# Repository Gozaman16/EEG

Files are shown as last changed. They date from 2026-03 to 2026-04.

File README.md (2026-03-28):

# EpiScreen EEG Electrode System

Semi-dry EEG electrode system with resin-printable silicone casting molds.
Designed for ISEF 2026.

## Components

| Component | File(s) | Description |
|---|---|---|
| EpiScreen electrode mold | `stl/episcreen_mold_bottom.stl` / `_top.stl` | 24 mm standard electrode, 2-part mold |
| NeoGuard neonatal mold | `stl/neoguard_mold_bottom.stl` / `_top.stl` | 15 mm neonatal electrode, 2-part mold |
| HairSite hair-contact mold | `stl/hairsite_mold_bottom.stl` / `_top.stl` | 24 mm electrode + 7 penetrating pins |
| ImpactGuard helmet adapter | `stl/impactguard_helmet_adapter.stl` | Snap-fit mount for sports helmets |
| Adult headband mount | `stl/headband_mount_adult.stl` | 22 mm elastic band clip, 24 mm electrode |
| Neonatal headband mount | `stl/headband_mount_neonatal.stl` | 16 mm silicone band clip, 15 mm electrode |

## Assembly Renders (300 DPI, ISEF-ready)

| Render | File | Description |
|---|---|---|
| Family photo | `renders/assembly_family.png` | All components side by side with scale bar & Turkish Lira coin reference |
| Exploded view | `renders/assembly_exploded.png` | All electrode layers separated vertically with assembly arrows |
| Cross-section | `renders/assembly_cross_section.png` | Internal features with full dimensioning and material callouts |

## Parametric Source (OpenSCAD)

All geometry is parametric via `scad/params.scad`. Edit dimensions there and
re-run `scripts/generate_stl.py` (uses `trimesh` + `manifold3d`) to regenerate STLs,
or open `.scad` files in OpenSCAD 2021+ for interactive editing.

```
scad/
  params.scad                 ← all dimensions in one place
  episcreen_mold_bottom.scad
  episcreen_mold_top.scad
  neoguard_mold_bottom.scad
  neoguard_mold_top.scad
  hairsite_mold_bottom.scad
  hairsite_mold_top.scad
  impactguard_helmet_adapter.scad
  headband_mount_adult.scad
  headband_mount_neonatal.scad
  assembly_family.scad
  assembly_exploded.scad
  assembly_cross_section.scad
```

## Regenerating outputs

```bash
# Install deps
pip install trimesh manifold3d numpy matplotlib pillow

# Generate all STL files
python3 scripts/generate_stl.py

# Render publication PNGs (300 DPI)
python3 scripts/render_family.py
python3 scripts/render_exploded.py
python3 scripts/render_cross_section.py
```

## Electrode Design Specs

### EpiScreen (24 mm)
- Outer diameter: 24 mm, total height: 10 mm
- FR-4 disk seat at 3 mm, reservoir ring ID/OD 13/19 mm × 1.5 mm
- 3× microchannel guide holes (Ø 0.6 mm, 37.5° angle)
- Spiral exposure platform: Ø 8 mm × 0.8 mm
- Cable exit: 3–4 mm wide funnel notch
- Mold: 32 mm OD, 4× Ø 2 mm alignment pins, 2× Ø 1 mm vent holes

### NeoGuard (15 mm)
- Outer diameter: 15 mm, total height: 8 mm
- FR-4 seat at 2.5 mm, reservoir ring ID/OD 8.5/12 mm × 1.2 mm
- Mold: 22 mm OD

### HairSite (24 mm + pins)
- Same body as EpiScreen, height 12 mm
- 7 penetrating pins: 1 centre + 6 on Ø 12 mm circle
- Pin diameter: 1.2 mm, length: 8 mm

## Print Settings (SLA/DLP)
- Layer height: 0.05 mm
- Resin: standard or flexible resin (depends on electrode flexibility needed)
- Supports: on mold exterior only — never inside cavity
- Minimum feature: 0.3 mm (microchannel holes, texture rings)

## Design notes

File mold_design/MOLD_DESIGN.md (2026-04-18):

# EEG Electrode Mold Design — EpiScreen / NeoGuard / HairSite

Two-part SLA-resin 3D-printable molds for casting semi-dry EEG electrodes
in Ecoflex 00-50 silicone. Three variants share a common architecture.

| Variant | Target use | Electrode OD | Pins |
|---|---|---|---|
| EpiScreen | Adult | 24 mm | — |
| NeoGuard | Neonatal | 15 mm | — |
| HairSite | Adult, through hair | 24 mm | 7 (1 centre + 6 on 6 mm radius) |

All mold SCAD sources live in `scad/`. This directory (`mold_design/`)
contains symlinks to those sources plus rendered STL / PNG assets for
non-mold parts (headband, impactguard, band guide).

## Files

| File | Description |
|---|---|
| `../scad/params.scad` | Shared parameters + utility modules |
| `../scad/episcreen_mold_bottom.scad`  | EpiScreen bottom mold |
| `../scad/episcreen_mold_top.scad` | EpiScreen top mold |
| `../scad/neoguard_mold_bottom.scad` | NeoGuard bottom mold |
| `../scad/neoguard_mold_top.scad` | NeoGuard top mold |
| `../scad/hairsite_mold_bottom.scad` | HairSite bottom mold |
| `../scad/hairsite_mold_top.scad` | HairSite top mold |

## Architecture

Each electrode is cast from **two silicone pours**, separated by a
barrier coat. The result is a **LOWER** silicone piece and an **UPPER**
silicone piece that mechanically interlock but are **separable for
service** (FR-4 swap, cleaning, inspection).

Key design decisions:

- **Funnel IS the reservoir.** A truncated-cone void inside the lower
  silicone holds the electrolyte. No separate reservoir ring.
- **Impedance ring** sits on the inner funnel wall, wetted
  automatically by electrolyte.
- **Lower silicone** owns FR-4, cables, funnel, sensing tip, impedance
  ring. **Upper silicone** is a thin lid with a refill port.
- **When opened, FR-4 stays with the lower half** and is accessible
  from above.

## Cross-Section Diagram

```
 ┌──────────────────────────┐
 │   UPPER SILICONE (lid)   │  ← refill port through this
 ├──────────────────────────┤  ← openable interlock interface
 │        FR-4 card         │  ← sits in recess on lower silicone's upper face
 ├──────────────────────────┤
 │                          │
 │      LOWER SILICONE      │
 │                          │
 │     ╲             ╱      │  ← funnel walls
 │      ╲   ▓▓▓▓▓   ╱       │  ← electrolyte (fills funnel = reservoir)
 │       ╲▓▓▓▓▓▓▓▓▓╱        │
 │        ╲▓▓▓▓▓▓▓╱         │
 │         ╲ ███ ╱          │  ← sensing tip (protrudes 0.1 mm)
 └──────────┴───┴───────────┘
           SKIN
```

## Parameter Table

| Parameter | EpiScreen | NeoGuard | HairSite  | Notes |
|---|---|---|---|---|
| Electrode OD (mm) | 24.0 | 15.0 | 24.0 | `*_OD` |
| Electrode height (mm)  | 10.0 | 8.0 | 12.0 | `*_H` |
| Mold OD (mm) | 32.0 | ~22.0 | 32.0 | = OD + 2·WALL + 4 |
| Bottom mold height | 5.0 | 4.0 | 6.0 | `*_BOT_H` |
| Top mold height | 6.5 | 5.5 | 7.5 | `*_TOP_H` |
| Pour hole Ø | 6.0 | 4.0 | 6.0 | |
| FR-4 Ø × thickness | 19×1.6 | 12×1.0 | 19×1.6 | flush with top of lower silicone |
| Funnel top Ø (FR-4) | 10.0 | 6.0 | 10.0 | `*_FUN_TOP_D` |
| Funnel bottom Ø (skin) | 18.0 | 11.0 | 18.0 | `*_FUN_BOT_D` |
| Funnel height | 3.0 | 2.5 | 3.0 | `*_FUN_H` |
| Sensing tip Ø | 3.0 | 2.0 | 3.0 | `*_SENSE_TIP_D` |
| Sensing tip protrude | 0.1 | 0.1 | 0.1 | past funnel bottom rim |
| Impedance ring width | 1.5 | 1.0 | 1.5 | on inner funnel wall |
| Impedance ring thick | 0.3 | 0.25 | 0.3 | generous — no "powdered sugar" tolerances |
| Cable strategy | C (2ch) | B (2×Ø)  | C (2ch) | see below |
| Cable channel W × H | 1.5 × 1.8 | Ø 1.5 | 1.5 × 1.8 | 1 mm cable + 0.5 mm clearance |
| Channel divider W | 2.0 | — | 2.0 | silicone divider (C only) |
| Alignment pins (count) | 4 | 3 | 4 | |
| Pin base × tip × h | 2.5/2.0/2.5 | 2.0/1.5/2.0 | 2.5/2.0/2.5 | conical, self-releasing |
| Hole Ø / depth | 2.3 / 2.8 | 1.8 / 2.3 | 2.3 / 2.8 | 0.3 mm clearances |
| Pin angles (deg) | 45,135,225,315 | 90,210,330 | 45,135,225,315 | avoid cable/vent/port |
| Refill port Ø | 2.0 | 2.0 | 2.0 | over funnel centre |

Global:

| Global parameter | Value | Was  | Why |
|---|---|---|-----|
| `CLEARANCE` | 0.5 | 0.3  | Ecoflex 00-50 needs more |
| `DRAFT` | 4° | 2° | Softer silicone needs more draft |
| Pillar Ø / h / pitch | 0.5 / 0.4 / 1.0 | — | hex pillar array (Y pattern) replaces concentric rings |

## Full Casting Procedure

1. **Barrier coat:** apply 2–3 thin coats clear acrylic spray to both
   mold halves (15 min between coats). This prevents SLA resin from
   inhibiting platinum-cure silicone. **Do NOT use vaseline** — it
   also inhibits the silicone.
2. **FR-4 + cables:** place FR-4 in the FR-4 recess in the bottom
   mold; thread cables through the cable tunnels; solder/attach to
   pads.
3. **Lower pour:** pour lower silicone (Ecoflex 00-50) into bottom
   mold. Cure **4 h @ 25 °C** or **1 h @ 45 °C**.
4. **Silicone-silicone separator:** apply **one thin coat** of clear
   acrylic spray on the top face of the cured lower silicone.
5. **Close and upper pour:** close top mold onto bottom mold. Pour
   upper silicone through the pour hole. Cure.
6. **Demold:** open molds via pry slots. Demold the electrode. Upper
   and lower silicone halves are separable at their interlock
   interface.

## SLA Post-Processing (per printed mold)

1. IPA wash 2× (5 min each)
2. UV post-cure 2 h + 60 °C
3. Air dry 24 h
4. Clear acrylic spray 2–3 thin coats, 15 min between each (barrier
   against silicone cure inhibition)

### Print orientation

- **Bottom mold:** natural orientation, cavity up.
- **Top mold:** *FLIPPED* — pins pointing up. Conical pins are
  self-supporting in this orientation. Printing with pins pointing
  down will fail (unsupported overhang).

## Rendering STLs

```bash
for f in scad/episcreen_mold_bottom.scad scad/episcreen_mold_top.scad \
         scad/neoguard_mold_bottom.scad  scad/neoguard_mold_top.scad \
         scad/hairsite_mold_bottom.scad  scad/hairsite_mold_top.scad; do
  out="${f%.scad}.stl"
  openscad -o "$out" "$f" || echo "FAILED: $f"
done

# Preview PNGs
for f in scad/*_mold_*.scad; do
  base="${f%.scad}"
  openscad --imgsize=800,800 --autocenter --viewall \
           -o "${base}_view.png" "$f"
done
```

Check manifold integrity with `admesh --no-check <file>.stl` or
MeshLab.

## Troubleshooting

| Symptom | Likely cause | Fix |
|---|---|-----|
| Silicone sticks to mold | Acrylic barrier coat incomplete / missed | Re-spray 2–3 coats, verify full coverage including cavity floor and funnel protrusion |
| Upper and lower silicone fuse together | Between-layer acrylic spray skipped or too heavy | Apply exactly **one thin** coat after lower silicone cures; let it flash off ~15 min before upper pour |
| Cables break or crush | Tunnel height < 1.8 mm or cable > 1 mm | Verify `CABLE_CH_H` ≥ 1.8 mm; insulated cable Ø ≤ 1 mm |
| Mold halves won't separate | Draft too low / clearance too tight | Check `DRAFT = 4`, `CLEARANCE = 0.5`; pry via V-notches at 45° / 135° / 225° / 315° |
| FR-4 drops out of lower silicone | Seat shelf too small or lip missing | Verify FR-4 Ø clearance = 0.5 mm; `EP_FR4_LIP` = 0.2 mm |
| Impedance ring doesn't contact electrolyte | Ring recess too shallow | Increase `EP_IMP_RING_T` or `EP_IMP_RING_W` — err generous |
| Cavity flash on skin side | Flash trap overflowing | Pour slightly less; trap captures small excess only |
| Upper silicone rotates on lower | Anti-rotation key not engaging | Inspect square socket for flash; verify `SIL_KEY_SIZE = 2.0` and clearance = 0.1 mm |

## Modifying Dimensions

All dimensions are parametrized in `../scad/params.scad`. Edit values
there and re-export STLs with the commands above. Follow the coding
style already in the file: uppercase names, 2-space indent inside
modules, section dividers with Unicode box characters, `EP_` /
`NG_` / `HS_` prefixes for variant-specific values.

**Generosity mandate:** when in doubt between two values, pick the
one with more clearance. Physical silicone tolerances, cable routing
realities, and SLA resolution limits all eat margin — generous
dimensions recover it.

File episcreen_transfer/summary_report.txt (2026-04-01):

EpiScreen Transfer Learning Pipeline - Summary Report
=======================================================

Model: Random Forest
Patients: 5 synthetic CHB-MIT
Sampling rate: 256 Hz, Window: 2s
Features: 13 (Delta Power, Theta Power, Alpha Power, Beta Power, Gamma Power, Line Length, Zero Crossing Rate, Hjorth Activity, Hjorth Mobility, Hjorth Complexity, Kurtosis, Skewness, Sample Entropy)

CHB-MIT Performance (LOPO CV):
  Sensitivity: 0.994 ± 0.013
  Specificity: 0.998 ± 0.004
  AUC: 1.000 ± 0.000
  FA rate: 4.0 ± 8.0 /hr
  Detection latency: 0.0 sec

Transfer to My Electrode:
  False alarm rate: 0.0 /hr
  Seizure sensitivity: 1.000
  Detection latency: 0.0 sec

Conclusion: Partially feasible

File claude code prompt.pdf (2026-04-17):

# Claude Code Task: EEG Electrode Mold Redesign (EpiScreen / NeoGuard / HairSite)

## Context

You are editing a parametric OpenSCAD mold project for semi-dry EEG electrodes. Repo: the EEG-main project you are checked out to. Manufacturing: SLA 3D-printed molds → Ecoflex 00-50 silicone casting.

DO NOT rewrite from scratch. The files already exist. Edit them surgically. Keep overall module structure, filenames, and coding style. Change only what this spec mandates.

Three variants:

episcreen — 24 mm adult electrode

neoguard — 15 mm neonatal electrode

hairsite — 24 mm adult electrode with 7 penetration pins through hair

Files to edit (all paths relative to repo root):

scad/params.scad (heavy changes)

scad/episcreen_mold_bottom.scad , scad/episcreen_mold_top.scad

scad/neoguard_mold_bottom.scad , scad/neoguard_mold_top.scad

scad/hairsite_mold_bottom.scad , scad/hairsite_mold_top.scad

mold_design/MOLD_DESIGN.md (rewrite to reflect new design)

The duplicate copies in mold_design/*.scad should be replaced with symlinks or rebuilt to match scad/*.scad . Investigate the duplication and handle it cleanly.

## Architectural Overview (read before editing)

Each electrode is cast from two silicone pours in a two-part mold, separated by a barrier coat. The result is a LOWER silicone piece and an UPPER silicone piece that mechanically interlock but are separable for service (FR-4 swap, cleaning, inspection).

Electrode cross-section (after demolding + assembly):

The funnel IS the reservoir. No separate reservoir ring.

The impedance ring sits on the inner funnel wall (wetted by electrolyte automatically).

The lower silicone owns FR-4, cables, funnel, sensing tip, impedance ring. The upper silicone is a thin lid with a refill port. When opened, FR-4 stays with the lower half and is accessible from above.

Casting procedure (for documentation, not for SCAD logic):

1. Apply 2–3 thin coats clear acrylic spray to both mold halves (15 min between coats). This is the barrier that prevents SLA resin from inhibiting platinum-cure silicone. Do NOT use vaseline — it inhibits the silicone.
2. Place FR-4 in the FR-4 recess in the bottom mold; thread cables through the cable tunnels; solder/attach to pads.
3. Pour lower silicone (Ecoflex 00-50) into bottom mold. Cure 4 h @ 25 °C or 1 h @ 45 °C.
4. Apply one thin coat of clear acrylic spray on the top face of the cured lower silicone (this is the silicone-silicone separator).
5. Close top mold onto bottom mold. Pour upper silicone through the pour hole. Cure.
6. Open molds via pry slots. Demold the electrode. Upper and lower silicone halves are separable at their interlock interface.

┌──────────────────────────┐
│ | UPPER SILICONE (lid) | │ ← refill port through this
├──────────────────────────┤ ← openable interlock interface
│ | | FR-4 card | │ ← sits in recess on lower silicone's upper face
├──────────────────────────┤
│ | | | │
│ | LOWER SILICONE | │
│ | | | │
│ | ╲ | ╱ | │ ← funnel walls
│ | ╲ ▓▓▓▓▓ ╱ | │ ← electrolyte (fills funnel = reservoir)
│ | ╲▓▓▓▓▓▓▓╱ | │
│ | ╲▓▓▓▓▓╱ | │
│ | ╲███╱ | │ ← sensing tip (protrudes 0.1 mm)
└──────────┴─┴─────────────┘
SKIN

## Design Decisions (implement all ten)

1. Mold separation / demolding

Update global parameters in scad/params.scad :

CLEARANCE = 0.5; | // was 0.3 — Ecoflex 00-50 needs more
DRAFT | = 4; | // was 2 — softer silicone needs more draft

Add pry slots to every mold (both halves), at the parting line. 4 × V-profile notches, 90° apart. Choose angular positions that avoid cable exits, vents, fill port, and alignment pins. A safe default: 45°, 135°, 225°, 315° (if cable exit is at 0°). Each slot: 3 mm wide × 2 mm deep, V-profile (triangular cross-section), centered on the parting line.

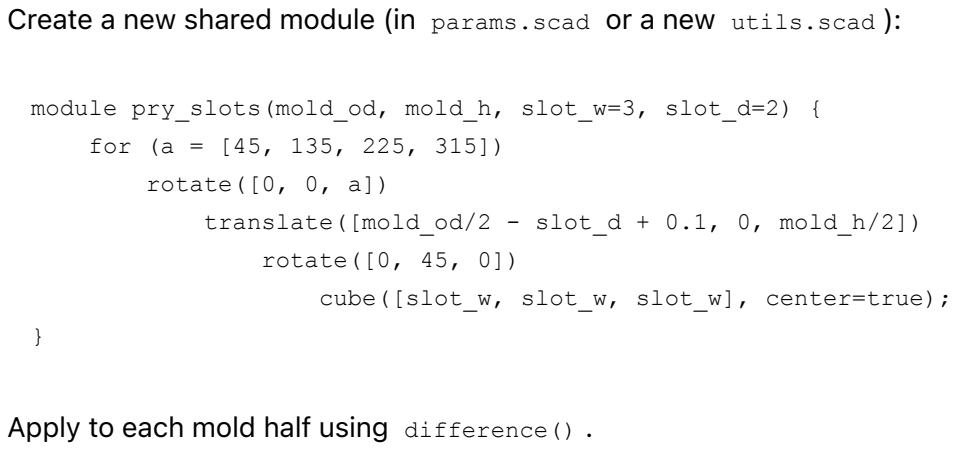
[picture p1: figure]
for (a = [45, 135, 225, 315]) rotate([0, 0, a]); rotate([0, 45, 0]) cube([slot_w, slot_w, slot_w], center=true);

Create a new shared module (in params.scad or a new utils.scad ):

module pry_slots(mold_od, mold_h, slot_w=3, slot_d=2) {

translate([mold_od/2 - slot_d + 0.1, 0, mold_h/2])

Apply to each mold half using difference() .

2. Cable exit channels — CRITICAL FIX

Current bug: cable exits are modeled as half-slots that span the parting line AND are positioned so they float in the mold wall (not reaching the cavity, barely breaking the outer wall). Users have been piercing cable holes manually with a needle. This is unacceptable.

Fix: cable exits are now fully enclosed through-hole tunnels inside the bottom mold only. The top of each tunnel is at bottom_mold_height - 0.3 mm , i.e., below the parting line. The top mold has NO cable exit features at all.

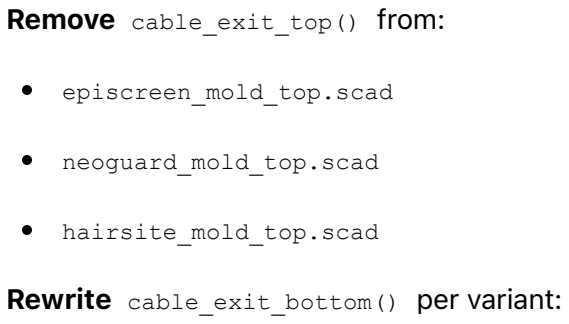
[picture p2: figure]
Remove cable_exit_top() from:; episcreen_mold_top.scad; neoguard_mold_top.scad; hairsite_mold_top.scad; Rewrite cable_exit_bottom() per variant:

EpiScreen and HairSite — C-strategy (single notch, two channels with divider):

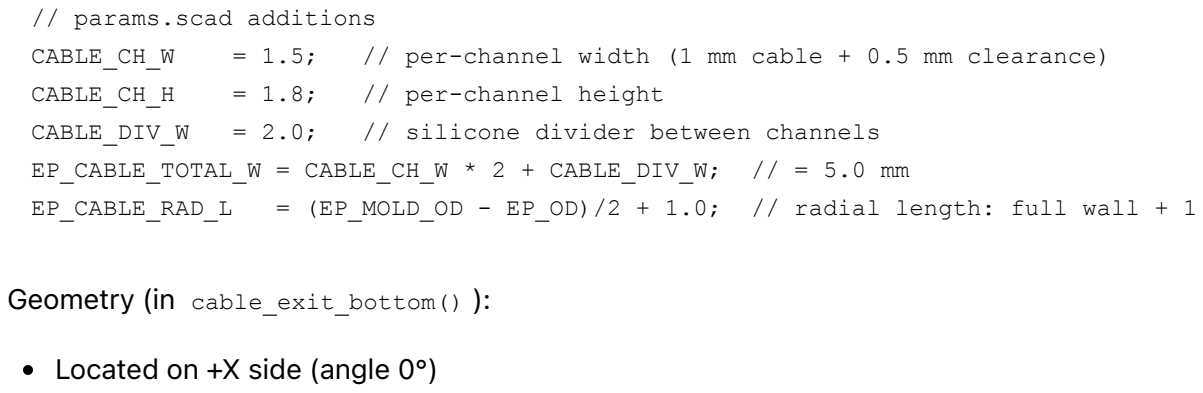
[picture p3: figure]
Geometry (in cable_exit_bottom() ):; Located on +X side (angle 0°); // params.scad additions; CABLE_CH_H; // per-channel height; CABLE_DIV_W; // silicone divider between channels

Two parallel rectangular through-tunnels, separated by 2 mm of mold material

Each tunnel: 1.5 mm (Y) × 1.8 mm (Z), running radially from cavity edge to outside

Z-centered at FR-4 level (so cable exits at FR-4 pad height)

Top surface of tunnels must be at Z ≤ (EP_BOT_H - 0.3) to stay below parting line

Small 1° flare on the outside opening (strain relief)

NeoGuard — B-strategy (two opposite round holes):

NG_CABLE_HOLE_D = 1.5; // 1 mm cable + 0.5 mm clearance
NG_CABLE_RAD_L = (NG_MOLD_OD - NG_OD)/2 + 1.0;

Geometry: two independent circular through-tunnels at 0° and 180°, each 1.5 mm diameter, running radially from cavity to outside. Z-centered at FR-4 level. Top of tunnel at Z ≤ (NG_BOT_H - 0.3).

Do NOT use C-strategy on NeoGuard. User decision: B is preferred for neonatal (mechanical balance, less crowding on 15 mm body).

3. Funnel-integrated electrode geometry

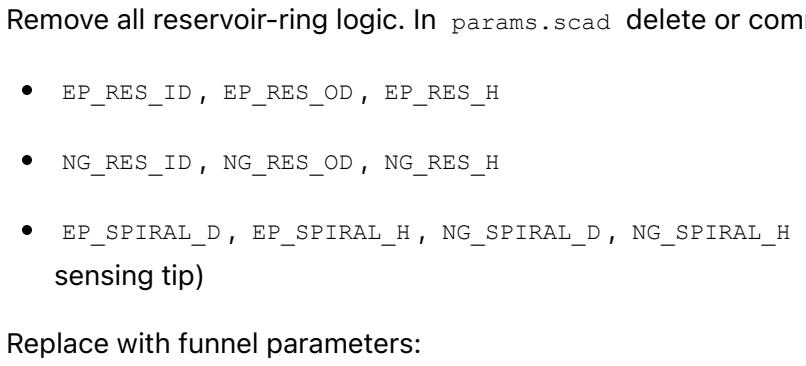
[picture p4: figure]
EP_RES_ID , EP_RES_OD , EP_RES_H; NG_RES_ID , NG_RES_OD , NG_RES_H; sensing tip); Replace with funnel parameters:

Remove all reservoir-ring logic. In params.scad delete or comment out:

EP_SPIRAL_D , EP_SPIRAL_H , NG_SPIRAL_D , NG_SPIRAL_H (spiral platform replaced by

CABLE_CH_W | = 1.5; | // per-channel width (1 mm cable + 0.5 mm clearance)

EP_CABLE_TOTAL_W = CABLE_CH_W * 2 + CABLE_DIV_W; // = 5.0 mm
EP_CABLE_RAD_L = (EP_MOLD_OD - EP_OD)/2 + 1.0; // radial length: full wall + 1 mm overhang

GENEROSITY MANDATE: Previous designs made the impedance ring space so tight “powdered sugar wouldn’t fit.” For every feature (impedance ring recess, sensing tip seat, FR-4 seat, refill port, cable channels), add at least 0.3 mm buffer beyond the geometric minimum. If you are uncertain whether a clearance is generous, make it larger. Err on the side of too much space, never too little.

Funnel implementation (in bottom mold):

The funnel is a truncated cone void inside the lower silicone, opening from FR-4 level (small end up) down to skin contact (large end down). In the mold, this is a positive feature (the mold has a conical protrusion where the silicone funnel void will be). The sensing tip is a smaller cylindrical void inside the funnel, centered.

Rough module structure (EpiScreen):

// EpiScreen funnel
EP_FUN_TOP_D | = 10.0; // FR-4 side (narrow)
EP_FUN_BOT_D | = 18.0; // skin side (wide)
EP_FUN_H | = 3.0;
EP_FUN_WALL | = 1.2;

// Sensing tip — small disk protruding from funnel center, past funnel bottom rim EP_SENSE_TIP_D = 3.0;
EP_SENSE_PROTRUDE = 0.1; // how far tip extends below funnel's bottom rim

// Impedance ring — on INNER funnel wall, GENEROUSLY sized
EP_IMP_RING_Z_FRAC = 0.5; // fraction of funnel height from top (0=FR4 side, 1=skin side)
EP_IMP_RING_W | = 1.5; // ring width along funnel wall (NOT cramped)
EP_IMP_RING_T | = 0.3; // ring thickness (protrusion into electrolyte)

// NeoGuard scaled
NG_FUN_TOP_D | = 6.0;
NG_FUN_BOT_D | = 11.0;
NG_FUN_H | = 2.5;
NG_FUN_WALL | = 1.0;
NG_SENSE_TIP_D | = 2.0;
NG_SENSE_PROTRUDE = 0.1;
NG_IMP_RING_Z_FRAC = 0.5;
NG_IMP_RING_W | = 1.0;
NG_IMP_RING_T | = 0.25;

// HairSite uses EP_ funnel dimensions (same 24 mm body)

module funnel_void() {
// inverted truncated cone: wide at bottom (skin side), narrow at top (FR-4 side)

Integrate these into the bottom mold’s electrode cavity. Top mold simply caps everything above FR-4 level (it does not contain funnel features).

4. Hexagonal pillar texture (Y-pattern) — replaces concentric rings

Remove skin_contact_texture (concentric ring module). Replace with hexagonal pillar array.

// params.scad
PILLAR_D | = 0.5; | // pillar diameter
PILLAR_H | = 0.4; | // pillar height
PILLAR_PITCH = 1.0; | // center-to-center spacing (hex grid)

module hex_pillar_texture(area_r, base_h) {
pitch = PILLAR_PITCH;
row_h = pitch * 0.866; | // sqrt(3)/2
n_rows = ceil(2 * area_r / row_h) + 2; n_cols = ceil(2 * area_r / pitch) + 2;
for (i = [-n_rows/2 : n_rows/2]) {
| y = i * row_h;
x_off = (i % 2 == 0) ? 0 : pitch/2;
for (j = [-n_cols/2 : n_cols/2]) {
x = j * pitch + x_off;
if (sqrt(x*x + y*y) < area_r - PILLAR_D/2) translate([x, y, base_h])

cylinder(d1 = EP_FUN_BOT_D, d2 = EP_FUN_TOP_D, h = EP_FUN_H); }

module sensing_tip_void() {
// narrow cylinder through center — silicone here becomes the protruding sensing seat cylinder(d = EP_SENSE_TIP_D, h = EP_FUN_H + EP_SENSE_PROTRUDE + 0.1);
}

module impedance_ring_void() {
// annular recess on the inner funnel wall at mid-height
// IMPORTANT: dimensioned GENEROUSLY — the previous design was too tight z = EP_FUN_H * (1 - EP_IMP_RING_Z_FRAC);
r_at_z = (EP_FUN_BOT_D/2)*(1 - EP_IMP_RING_Z_FRAC)
+ (EP_FUN_TOP_D/2)*EP_IMP_RING_Z_FRAC;
translate([0, 0, z - EP_IMP_RING_W/2]) difference() {
cylinder(r = r_at_z + EP_IMP_RING_T, h = EP_IMP_RING_W); cylinder(r = r_at_z, h = EP_IMP_RING_W + 0.1);
}
}

cylinder(d = PILLAR_D, h = PILLAR_H, center = false); }
}
}

Apply to the skin-contact surface (the flat annular area surrounding the funnel’s bottom opening) in all three variants:

episcreen_mold_bottom.scad

neoguard_mold_bottom.scad

hairsite_mold_bottom.scad

Currently only EpiScreen calls the texture module. Add calls to NeoGuard and HairSite — this was a real bug.

HairSite special case: use difference() to subtract 0.5 mm-radius cylindrical exclusion zones around each of the 7 pin positions, so the pillars don’t interfere with the pins.

The pillars are positive features on the skin-contact side of the silicone (mold has holes; silicone gets raised pillars).

5. Alignment pins — improve, do not remove

Replace current pin parameters:

// EpiScreen / HairSite
PIN_D_BASE = 2.5;
PIN_D_TIP | = 2.0;
PIN_H | = 2.5;
HOLE_D | = 2.3; | // 0.3 mm radial clearance at tip
HOLE_DEPTH = 2.8; | // 0.3 mm axial clearance
PIN_R | = 4;
PIN_ANGLES = [45, 135, 225, 315]; // avoid cable notch at 0°

// NeoGuard — scaled down, only 3 pins (not 4 — not enough room on 22 mm OD) NG_PIN_D_BASE = 2.0;
NG_PIN_D_TIP = 1.5;
NG_PIN_H | = 2.0;
NG_HOLE_D | = 1.8;
NG_HOLE_DEPTH = 2.3;
NG_PIN_R | = 3;
NG_PIN_ANGLES = [90, 210, 330]; | // avoid cable exits at 0° and 180°

Pin geometry: conical (base wider than tip) for self-release during demolding.

module alignment_pin_male(d_base, d_tip, h) {
cylinder(d1 = d_base, d2 = d_tip, h = h, center = false); }
module alignment_hole(d, depth) {
cylinder(d = d, h = depth, center = false);
}

The top mold gets male pins (extruding downward into bottom mold). The bottom mold gets matching holes.

SLA print-orientation note (add as comment in every top-mold .scad):

Print the TOP mold flipped — pins pointing UP during printing. Conical geometry is self-supporting in that orientation. Printing with pins pointing down will fail (unsupported overhang).

6. Flash trap (NOT for alignment — alignment is done by pins)

Small perimeter groove on the bottom mold’s upper rim, inside the outer edge, to catch stray silicone.

Apply in each bottom mold, at the top face. Top mold has no matching feature.

7. Silicone interlock (openable lower + upper silicone halves)

Features IN THE MOLD that create features IN THE SILICONE to allow the two silicone halves to interlock mechanically but remain separable.

FLASH_GROOVE_W = 0.5;
FLASH_GROOVE_D = 0.5;

module flash_trap(mold_od) {
// cut a shallow annular groove near the outer edge of the bottom mold's top face translate([0, 0, -0.01])
difference() {
cylinder(d = mold_od - 2*WALL + 0.5, h = FLASH_GROOVE_D + 0.02);
cylinder(d = mold_od - 2*WALL + 0.5 - 2*FLASH_GROOVE_W, h = FLASH_GROOVE_D + 0.02); }
}

// params.scad
SIL_LIP_H | = 1.5; | // perimeter lip height (raised feature on top face of lower silicone)
SIL_LIP_W | = 1.5; | // lip radial width
SIL_GROOVE_CLEAR = 0.1; // radial clearance lip-to-groove
SIL_KEY_SIZE | = 2.0; | // anti-rotation key: 2x2 mm square

Lower mold (in *_mold_bottom.scad ) must create, on the top face of the lower silicone:

1. A raised perimeter lip running around the top of the silicone, just inside the outer edge of the silicone body.
2. An anti-rotation key — a small raised 2×2 mm square protrusion at SIL_KEY_ANGLE .
3. A service notch — a small tab at SIL_SERVICE_ANGLE for fingernail/spatula access when opening.

In the mold, these are voids in the bottom mold’s cavity ceiling (the mold’s inner top surface): a ring-shaped void for the lip, a square void for the key, a tab void for the service feature. Silicone flows into the voids → becomes raised features on the silicone.

Top mold (in *_mold_top.scad ) must create matching negatives on the bottom face of the upper silicone:

1. A perimeter groove matching the lip geometry, with SIL_GROOVE_CLEAR radial clearance (groove is 0.1 mm wider + 0.1 mm deeper than the lip).
2. A square socket matching the anti-rotation key (again, 0.1 mm clearance).
3. A complementary gap at the service notch position.

In the mold, these are solid protrusions extending down from the top mold’s inner upper surface into what will become upper silicone. Silicone flows around them → becomes grooves/sockets in the silicone.

Do not use undercuts or snap-fit geometry — Ecoflex 00-50 is too soft (Shore ~00-50 ≈ Shore A 5). Use straight lip-and-groove press fit only. The halves hold together by friction + mechanical keying, not by elastic snap.

8. FR-4 seat (in lower silicone)

Ensure the FR-4 sits in a recess in the lower silicone such that its top face is flush with or slightly below the top of the lower silicone (to leave a flat openable interface).

Adjust FR-4 Z positions:

// FR-4 top face at top of lower silicone body
EP_FR4_Z = EP_BOT_H - EP_FR4_T; | // = 5 - 1.6 = 3.4 mm
NG_FR4_Z = NG_BOT_H - NG_FR4_T; | // = 4 - 1.0 = 3.0 mm
SIL_KEY_ANGLE = 90; | // 12 o'clock (adjust if it conflicts with other features)
SIL_SERVICE_W = 2.0; | // service notch for prying halves apart
SIL_SERVICE_H = 1.0;
SIL_SERVICE_ANGLE = 270; // 6 o'clock

Current code has FR-4 embedded mid-lower-silicone, which prevents access after opening. New position: FR-4 is at the TOP of the lower silicone, accessible when the upper half is removed.

The lower mold creates a square/circular shelf that the FR-4 rests on; silicone fills AROUND the FR-4 (not over it). The top of the FR-4 remains exposed once the lower silicone cures.

9. Refill port (in upper silicone / top mold only)

A 2 mm vertical through-hole in the top mold creates a refill port in the upper silicone. User can add/refresh electrolyte through this port without opening the halves.

REFILL_PORT_D = 2.0;

Position: over the funnel center (so electrolyte drops straight down into funnel reservoir).

10. Documentation

Rewrite mold_design/MOLD_DESIGN.md to reflect the new design. Include:

Updated cross-section ASCII diagram

New parameter table (all dimensions for all three variants)

Full casting procedure (the one listed above in “Architectural Overview”)

SLA post-processing steps (IPA wash, UV cure, acrylic spray)

Troubleshooting notes (e.g., “if silicone sticks to mold, check acrylic barrier coverage; if halves fuse together, check between-silicone separator application”)

Also add, at the top of every edited .scad file, a block comment:

// ═════════════════════════════════════════════════════════════ // SLA PRINT:
// | Bottom mold: natural orientation (cavity up)
// | Top mold: | FLIPPED (pins up — self-supporting)
// POST-PROCESS:
// | 1. IPA wash 2× (5 min each)
// | 2. UV post-cure 2 h + 60 °C
// | 3. Air dry 24 h
// | 4. Clear acrylic spray 2–3 thin coats, 15 min between
// | (barrier against silicone cure inhibition)
// CAST:
// Silicone: Ecoflex 00-50 (platinum-cure, Shore 00-50)

// | Sequential pour: bottom first (4 h @ 25 °C or 1 h @ 45 °C)
// | Between silicone layers: 1 thin coat acrylic spray, 15 min
// | NEVER use vaseline — inhibits platinum cure
// ═════════════════════════════════════════════════════════════

## Build / render verification

After editing, verify each mold compiles and renders:

for f in scad/episcreen_mold_bottom.scad scad/episcreen_mold_top.scad \
| scad/neoguard_mold_bottom.scad scad/neoguard_mold_top.scad \
| scad/hairsite_mold_bottom.scad scad/hairsite_mold_top.scad; do
| out="${f%.scad}.stl"
| openscad -o "$out" "$f" || echo "FAILED: $f"
done

Render preview PNGs (top-down + cross-section) for each mold:

for f in scad/*_mold_*.scad; do
| base="${f%.scad}"
| openscad --imgsize=800,800 --autocenter --viewall \
| -o "${base}_view.png" "$f"
done

Update mold_design/ with the new STLs and PNGs.

## Deliverables checklist

Before declaring done, verify every item:

All 6 *_mold_*.scad files compile to valid STL

STL files are manifold (spot-check with admesh --no-check or meshlab )

Cable exits: through-tunnels in BOTTOM molds only, top of tunnel ≤ 0.3 mm below parting line

cable_exit_top() removed from all three top molds

EpiScreen + HairSite: C-strategy (1 notch, 2 channels, 2 mm divider)

NeoGuard: B-strategy (2 opposite round holes)

Funnel geometry present in all three bottom molds (FR-4 side narrow, skin side wide)

Sensing tip protrudes 0.1 mm past funnel bottom rim

Impedance ring recess on INNER funnel wall, at mid-height, with GENEROUS sizing (≥ 0.3 mm buffer)

Reservoir ring code removed — funnel IS the reservoir

Hex pillar texture applied to ALL THREE bottom molds (not just EpiScreen)

HairSite texture excludes pin regions

Alignment pins: conical (base > tip), with 0.3 mm clearance in holes

EpiScreen/HairSite: 4 pins; NeoGuard: 3 pins

Pin angles avoid cable exits, vents, fill port

Pry slots in every mold (4 per mold, 90° apart, avoiding other features)

Flash trap groove on bottom molds only

Silicone interlock: lip (lower) + groove (upper) + anti-rotation key + service notch

FR-4 seat positioned so FR-4 top face is flush with top of lower silicone

Refill port (2 mm) in all three top molds, over funnel center

Every edited .scad has the SLA/cast comment block at top

mold_design/MOLD_DESIGN.md rewritten

## Notes on style and behavior

Follow the existing OpenSCAD coding conventions in params.scad : uppercase parameter names, 2-space indent inside modules, section dividers with Unicode box characters.

Where a parameter is shared across variants, put it in params.scad under a “global” section. Where it’s variant-specific, keep the EP_ , NG_ , HS_ prefixes.

Use $fn = 120 for smooth cylinders (already global).

If you encounter ambiguity or a parameter conflict, choose the GENEROUS option and
note it in a comment ( // NOTE: sized generously — was too tight in previous generation ).

When a parameter replaces or removes an old one, delete the old entry cleanly (do not leave dead code or // deprecated comments lying around, except at the top of the file where a short changelog is useful).

## One final reminder

The user running this project has been burned repeatedly by cramped dimensions. When in doubt between two values, pick the one with more clearance. Physical silicone tolerances, cable routing realities, and SLA resolution limits all eat margin — generous dimensions recover that margin.

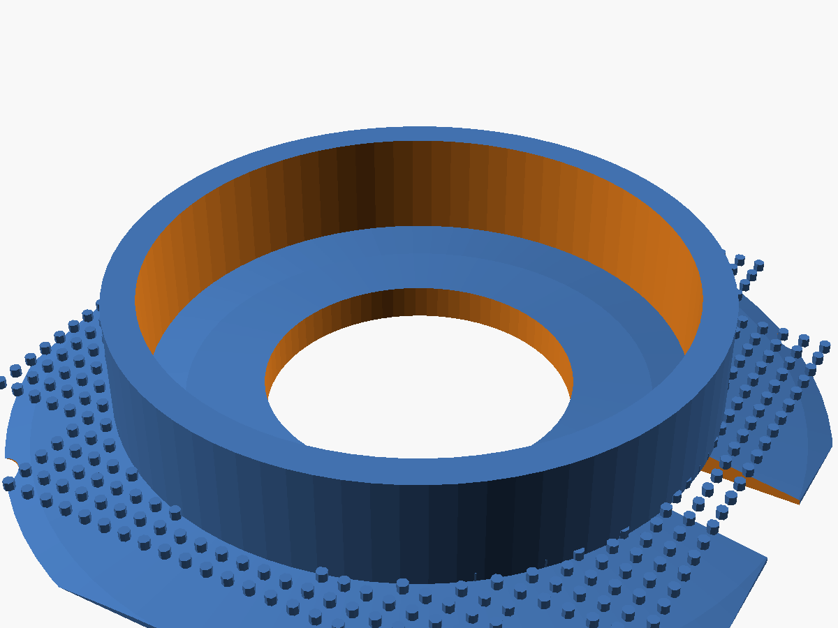
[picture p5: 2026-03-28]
mold_design/impactguard_helmet_adapter_view.png

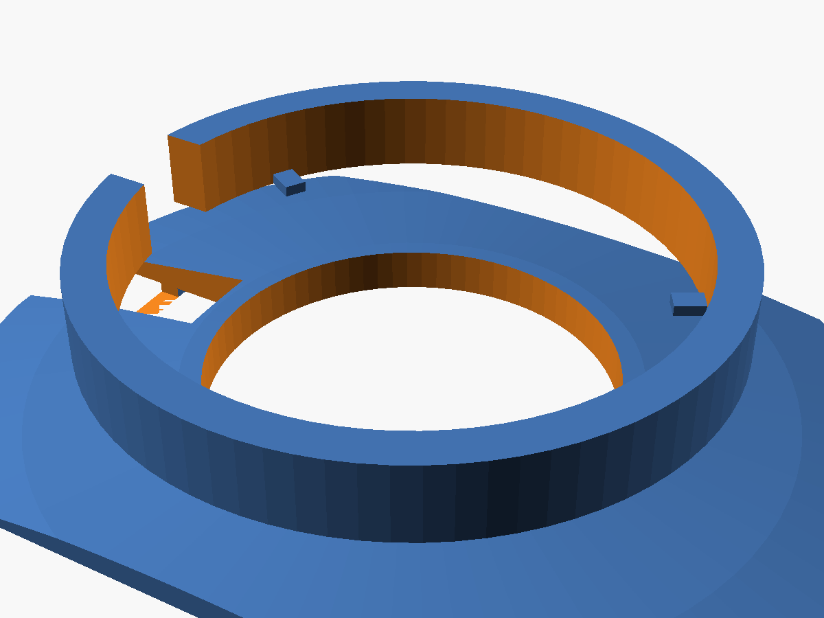
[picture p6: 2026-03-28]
mold_design/headband_mount_adult_view.png

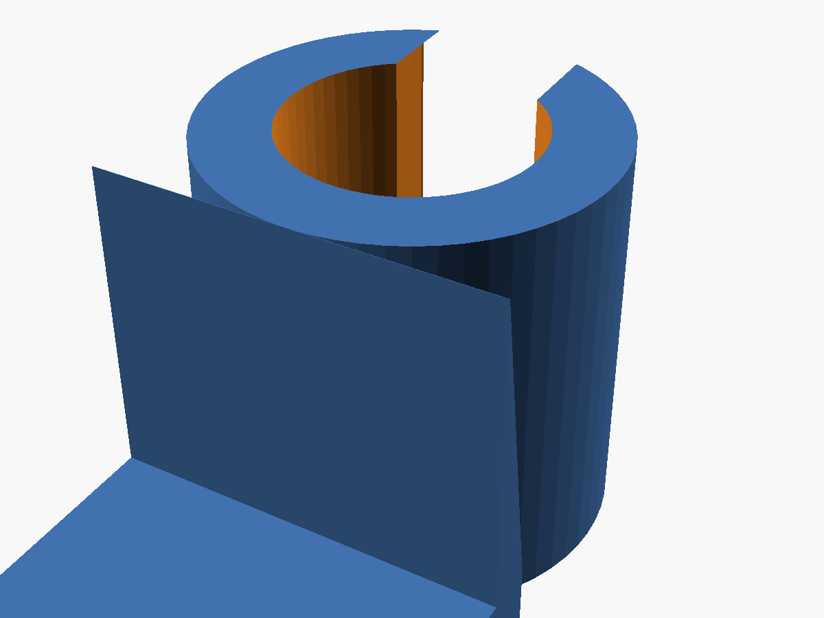
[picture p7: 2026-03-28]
mold_design/impactguard_cable_clip_view.png

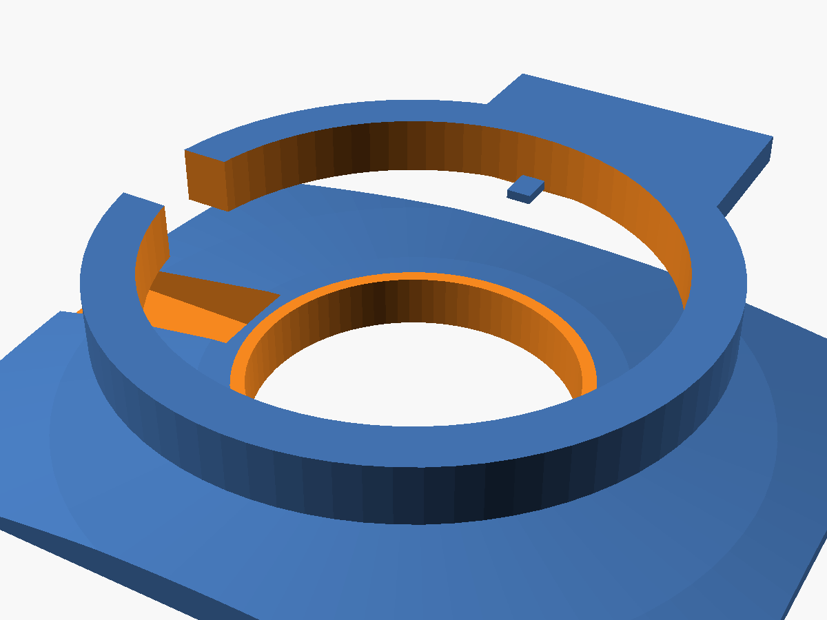
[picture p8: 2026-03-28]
mold_design/headband_mount_neonatal_view.png

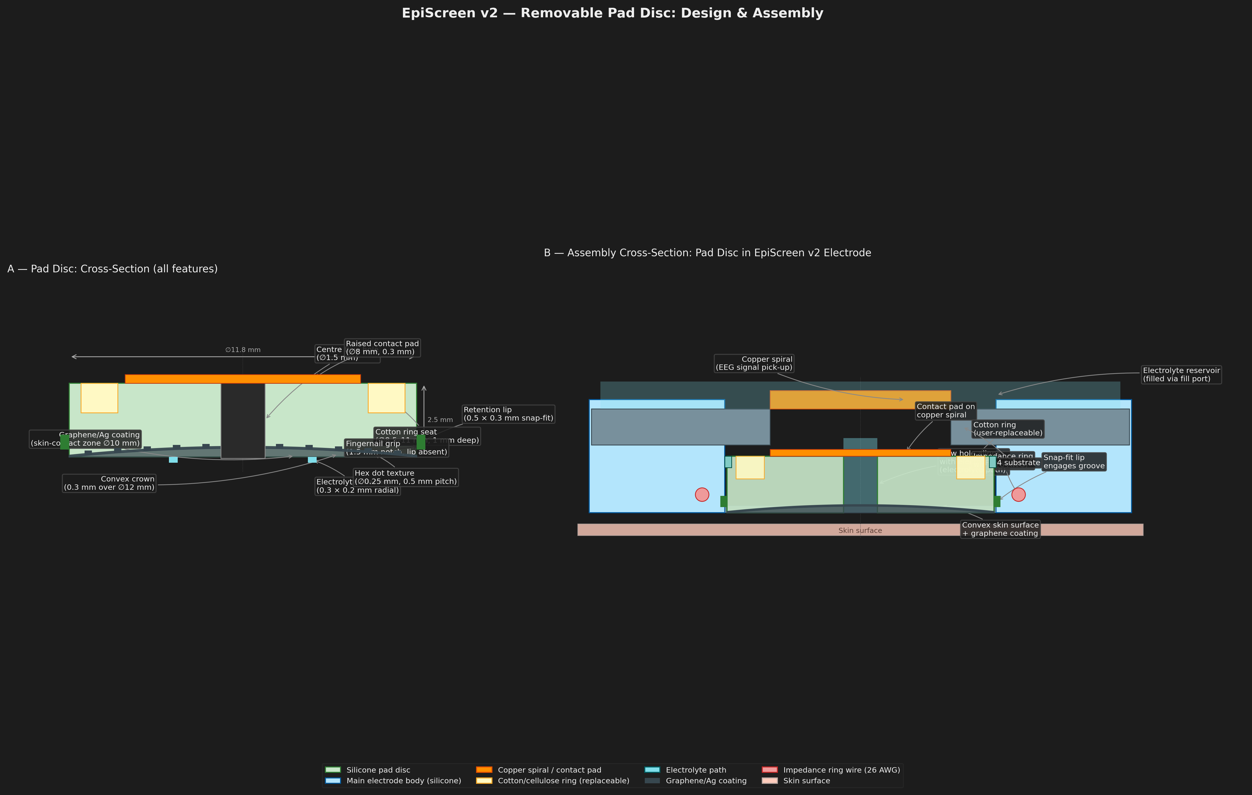
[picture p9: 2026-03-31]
renders/pad_disc_cross_section.png

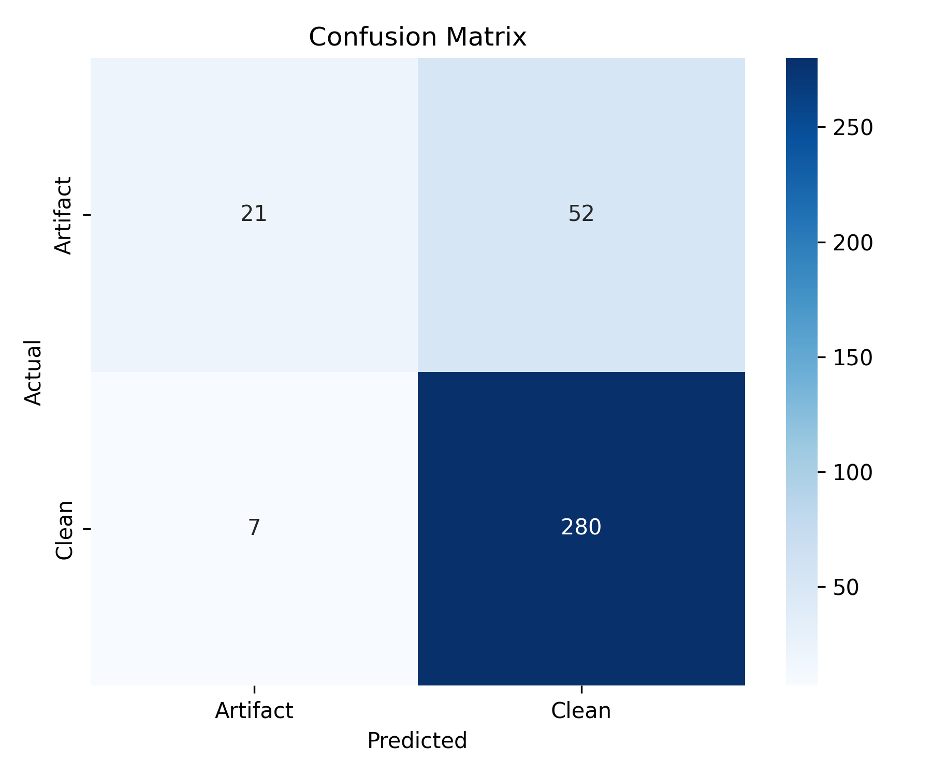
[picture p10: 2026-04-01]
signal_quality_classifier/fig3_confusion_matrix.png

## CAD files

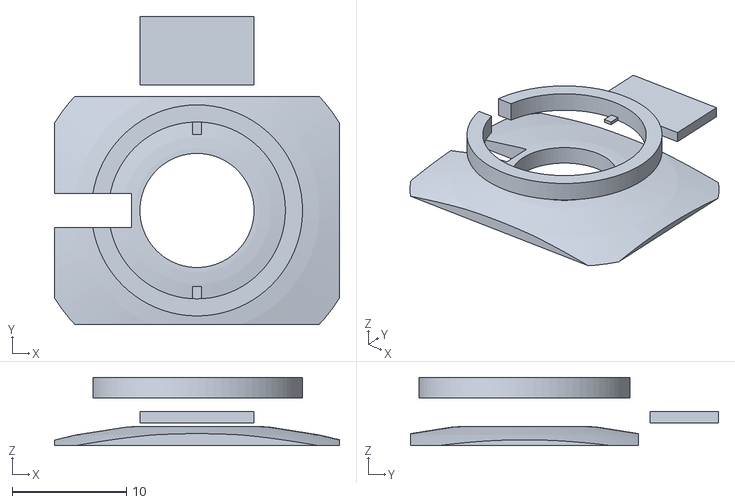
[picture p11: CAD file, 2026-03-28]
mold_design/headband_mount_neonatal.stl
25.0 x 27.0 x 6.00

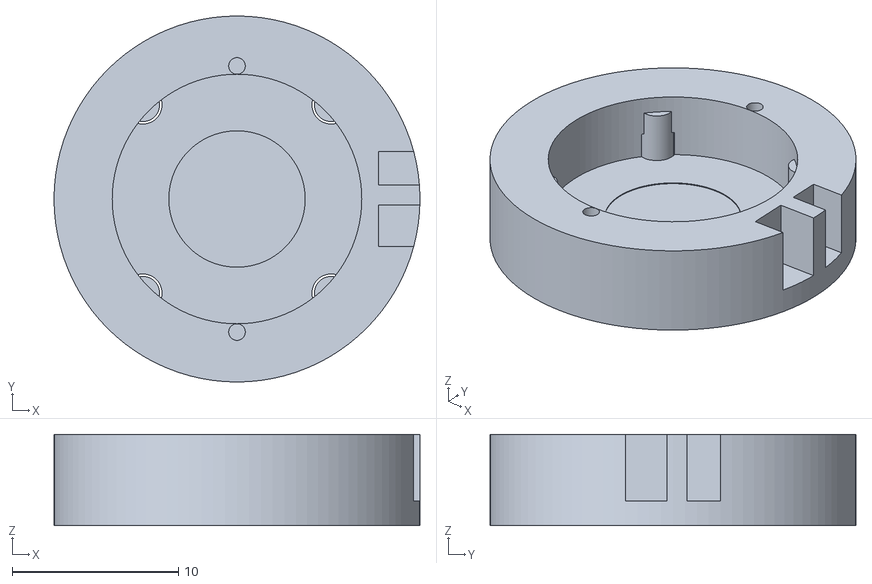
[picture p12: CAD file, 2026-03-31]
stl/neoguard_v2_mold_top.stl
22.0 x 22.0 x 5.50

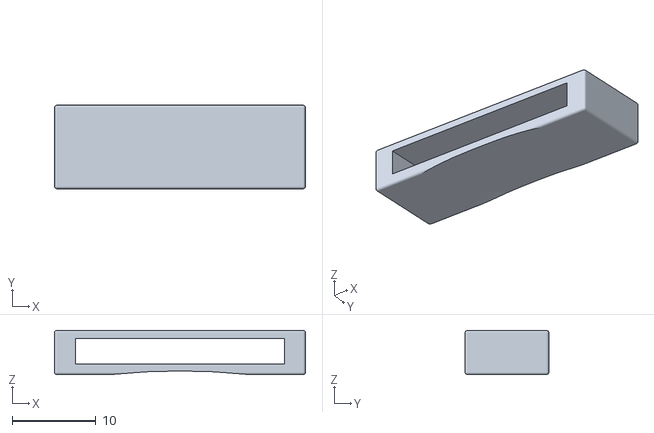
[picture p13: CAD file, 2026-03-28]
mold_design/band_guide_clip.stl
30.0 x 10.00 x 5.30

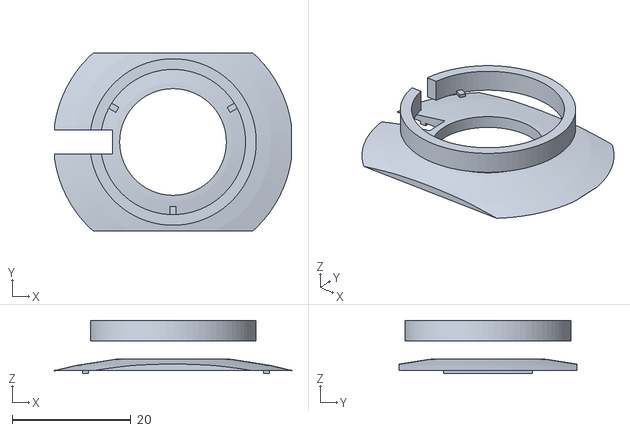
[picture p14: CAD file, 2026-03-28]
mold_design/headband_mount_adult.stl
40.0 x 30.0 x 9.00

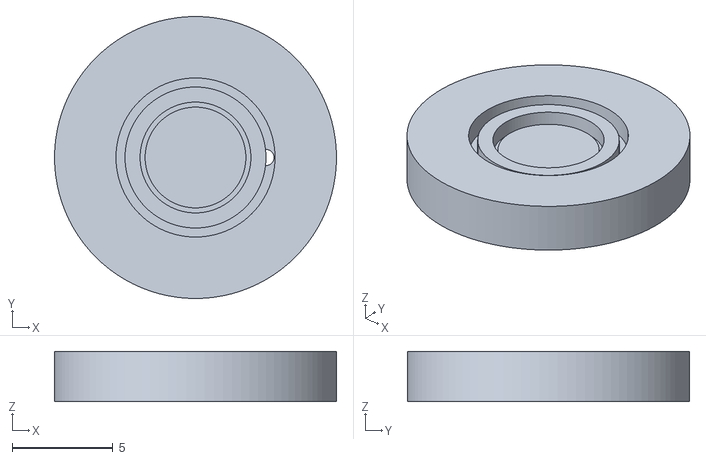
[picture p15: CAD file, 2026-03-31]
stl/neoguard_pad_disc_mold_top.stl
14.0 x 14.0 x 2.50

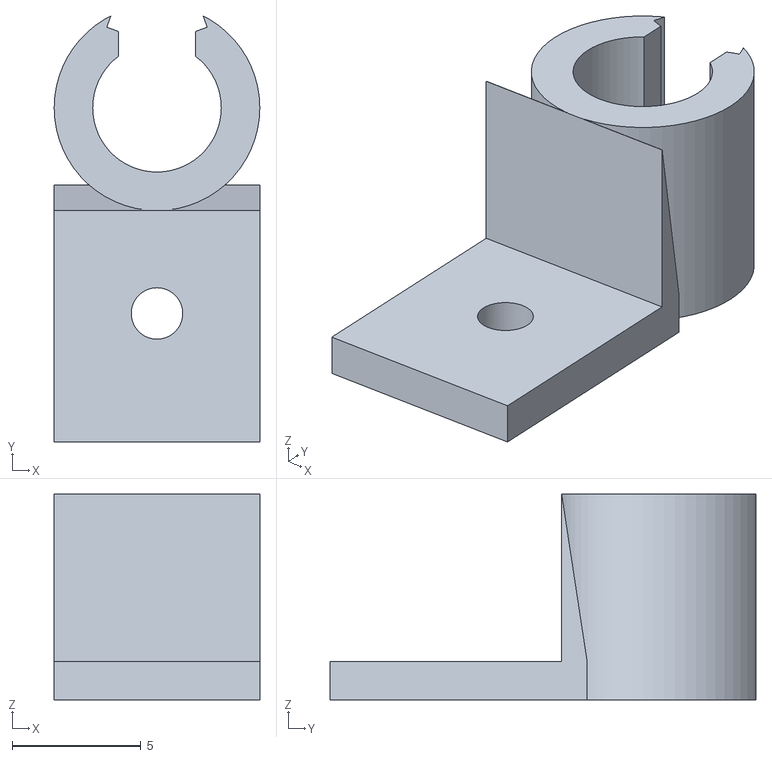
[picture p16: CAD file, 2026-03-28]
mold_design/impactguard_cable_clip.stl
8.00 x 16.6 x 8.00

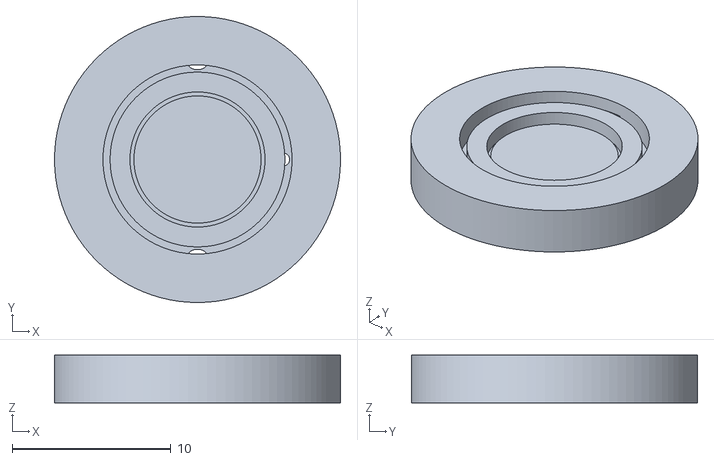
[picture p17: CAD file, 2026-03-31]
stl/pad_disc_mold_top.stl
18.0 x 18.0 x 3.00

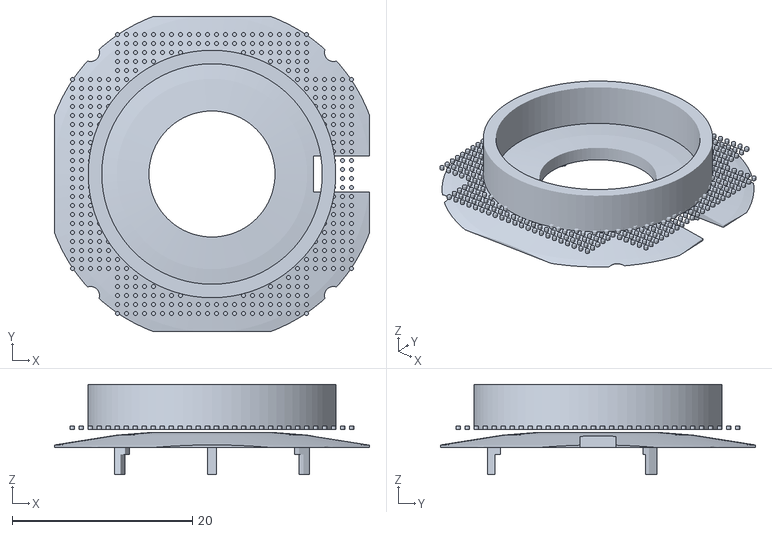
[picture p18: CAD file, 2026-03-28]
mold_design/impactguard_helmet_adapter.stl
35.0 x 35.0 x 10.0

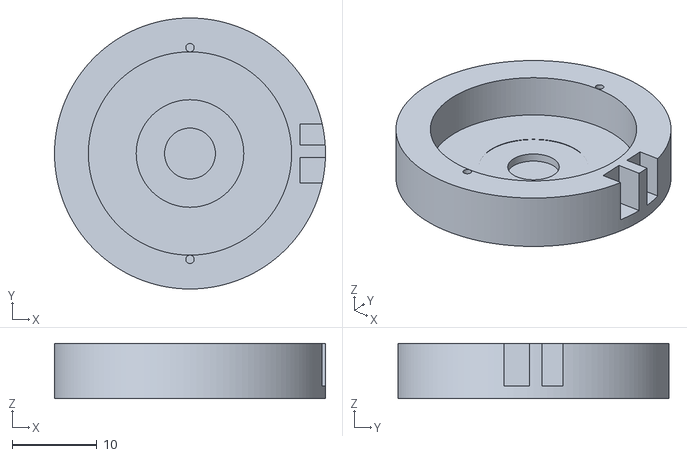
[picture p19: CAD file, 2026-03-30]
stl/episcreen_v2_mold_top.stl
32.0 x 32.0 x 6.50

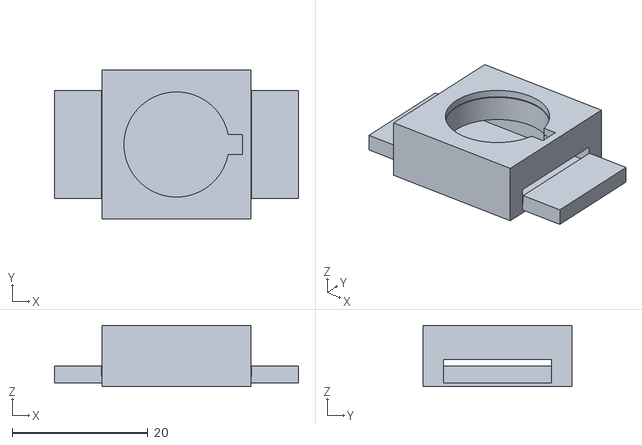
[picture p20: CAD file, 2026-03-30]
stl/headband_mount_neonatal.stl
36.0 x 22.0 x 9.00

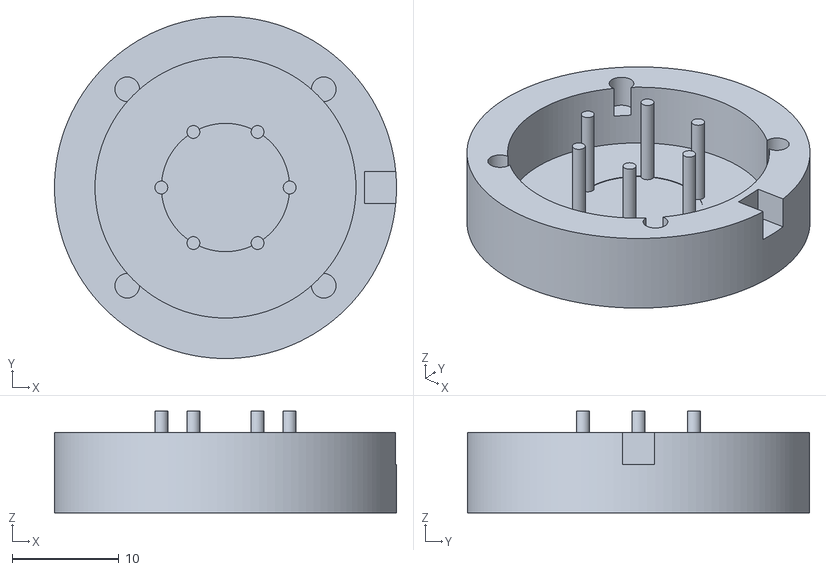
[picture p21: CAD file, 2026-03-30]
stl/hairsite_mold_bottom.stl
32.0 x 32.0 x 9.50

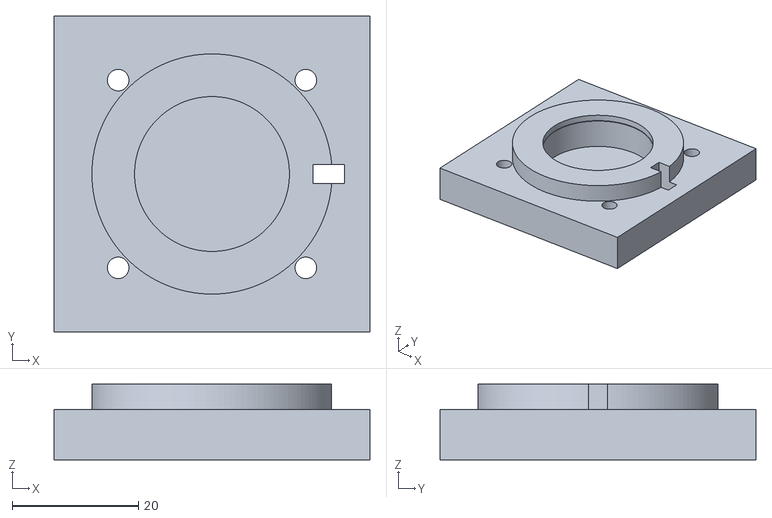
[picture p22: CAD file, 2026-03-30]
stl/impactguard_helmet_adapter.stl
50.0 x 50.0 x 12.0

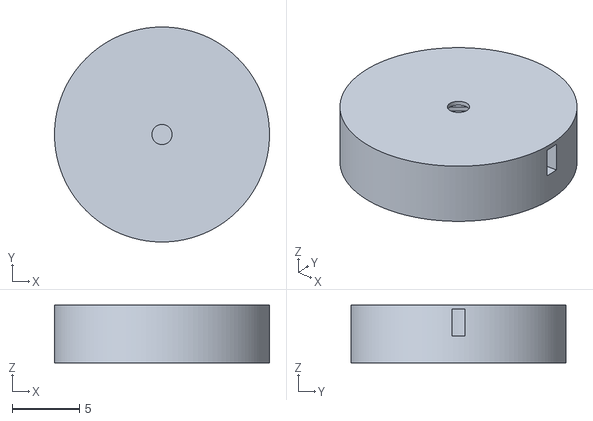
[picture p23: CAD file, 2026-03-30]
stl/pad_disc_mold.stl
16.0 x 16.0 x 4.30

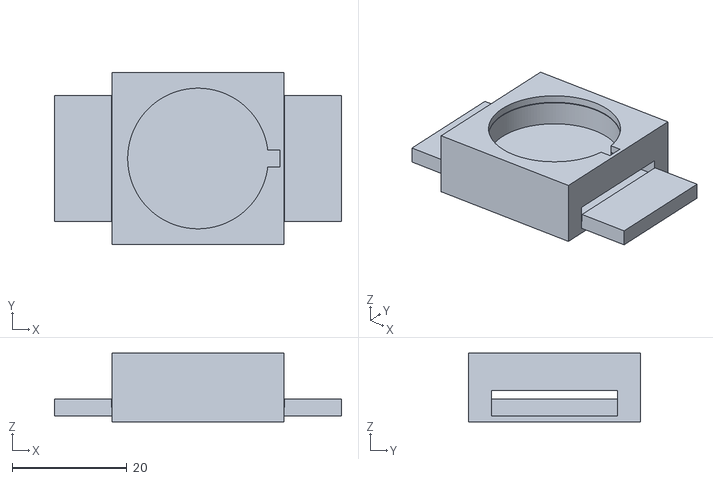
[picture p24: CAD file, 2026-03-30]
stl/headband_mount_adult.stl
50.0 x 30.0 x 12.0

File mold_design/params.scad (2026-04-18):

../scad/params.scad

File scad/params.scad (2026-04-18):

// ═════════════════════════════════════════════════════════════
// EpiScreen / NeoGuard / HairSite — Shared Parameters
// Project: EpiScreen / NeoGuard / HairSite / ImpactGuard
// License: MIT
// ─────────────────────────────────────────────────────────────
// Changelog (funnel-integrated redesign):
//   • CLEARANCE 0.3 → 0.5 (Ecoflex 00-50 needs more room)
//   • DRAFT     2   → 4   (softer silicone needs more draft)
//   • Reservoir rings and spiral platforms removed — the funnel
//     IS the reservoir. Impedance ring sits on funnel inner wall.
//   • Cable exits are now fully enclosed through-tunnels in the
//     bottom mold only (top mold has no cable features).
//   • Concentric ring texture replaced by hexagonal pillar array.
//   • Alignment pins are now conical with generous clearance.
//   • Pry slots, flash trap, silicone interlock, refill port added.
// ═════════════════════════════════════════════════════════════

// ── Global print-quality settings ──────────────────────────
$fn        = 120;    // Cylinder facets (high quality)
FILLET     = 0.2;    // Edge fillet for printability (mm)
CLEARANCE  = 0.5;    // Mating-surface clearance — was 0.3; Ecoflex 00-50 needs more
WALL       = 1.5;    // Minimum wall thickness (mm)
DRAFT      = 4;      // Draft angle on vertical walls — was 2; softer silicone needs more

// ── Vent hole geometry ─────────────────────────────────────
VENT_D     = 1.0;    // Vent hole diameter (mm)

// ── Cable tunnel geometry (C-strategy for EP / HS) ─────────
CABLE_CH_W    = 1.5;                          // per-channel width (1 mm cable + 0.5 mm clearance)
CABLE_CH_H    = 1.8;                          // per-channel height
CABLE_DIV_W   = 2.0;                          // silicone divider between channels
CABLE_FLARE   = 1;                            // deg flare on outside opening (strain relief)

// ── Refill port (upper silicone) ───────────────────────────
REFILL_PORT_D = 2.0;                          // vertical through-hole in top mold

// ── Hexagonal pillar texture (skin contact) ────────────────
PILLAR_D      = 0.5;                          // pillar diameter
PILLAR_H      = 0.4;                          // pillar height
PILLAR_PITCH  = 1.0;                          // center-to-center (hex grid)

// ── Pry slots (at parting line, 4× per mold) ───────────────
PRY_SLOT_W    = 3.0;                          // width along parting line
PRY_SLOT_D    = 2.0;                          // radial depth

// ── Flash trap groove (bottom mold, top face) ──────────────
FLASH_GROOVE_W = 0.5;
FLASH_GROOVE_D = 0.5;

// ── Silicone interlock (lip + groove + key + service notch) ──
SIL_LIP_H        = 1.5;                       // raised lip height on top of lower silicone
SIL_LIP_W        = 1.5;                       // lip radial width
SIL_GROOVE_CLEAR = 0.1;                       // radial clearance lip↔groove
SIL_KEY_SIZE     = 2.0;                       // 2×2 mm anti-rotation key
SIL_KEY_ANGLE    = 90;                        // 12 o'clock
SIL_SERVICE_W    = 2.0;                       // service notch tab width
SIL_SERVICE_H    = 1.0;                       // tab height
SIL_SERVICE_ANGLE = 270;                      // 6 o'clock

// ═════════════════════════════════════════════════════════════
// EpiScreen standard electrode (24 mm adult)
// ═════════════════════════════════════════════════════════════
EP_OD         = 24.0;
EP_H          = 10.0;
EP_MOLD_OD    = EP_OD + 2*WALL + 4.0;         // = 32 mm mold OD
EP_BOT_H      = 5.0;
EP_TOP_H      = EP_H - EP_BOT_H + WALL;
EP_POUR_D     = 6.0;                          // silicone pour hole (upper)

// FR-4 seat — sits at top of lower silicone, accessible when opened
EP_FR4_D      = 19.0;
EP_FR4_T      = 1.6;
EP_FR4_Z      = EP_BOT_H - EP_FR4_T;          // = 3.4 mm (top face flush with top of lower silicone)
EP_FR4_LIP    = 0.2;                          // centering lip

// Funnel (replaces reservoir ring + spiral platform)
EP_FUN_TOP_D     = 10.0;                      // FR-4 side (narrow)
EP_FUN_BOT_D     = 18.0;                      // skin side (wide)
EP_FUN_H         = 3.0;
EP_FUN_WALL      = 1.2;

// Sensing tip — disk protruding 0.1 mm past funnel bottom rim
EP_SENSE_TIP_D    = 3.0;
EP_SENSE_PROTRUDE = 0.1;

// Impedance ring — INNER funnel wall, GENEROUSLY sized
EP_IMP_RING_Z_FRAC = 0.5;                     // 0 = FR-4 side, 1 = skin side
EP_IMP_RING_W      = 1.5;                     // width along funnel wall (NOT cramped)
EP_IMP_RING_T      = 0.3;                     // radial protrusion into electrolyte

// Cable exit (C-strategy — single notch, two channels, divider)
EP_CABLE_TOTAL_W = CABLE_CH_W*2 + CABLE_DIV_W;    // = 5.0 mm
EP_CABLE_RAD_L   = (EP_MOLD_OD - EP_OD)/2 + 1.0;  // full wall + 1 mm overhang

// Alignment pins (conical, 4×, avoid cable notch at 0°)
PIN_D_BASE    = 2.5;
PIN_D_TIP     = 2.0;
PIN_H         = 2.5;
HOLE_D        = 2.3;                          // 0.3 mm radial clearance at tip
HOLE_DEPTH    = 2.8;                          // 0.3 mm axial clearance
PIN_R         = 4;                            // number of pins
PIN_ANGLES    = [45, 135, 225, 315];

// ═════════════════════════════════════════════════════════════
// NeoGuard neonatal electrode (15 mm)
// ═════════════════════════════════════════════════════════════
NG_OD         = 15.0;
NG_H          = 8.0;
NG_MOLD_OD    = NG_OD + 2*WALL + 4.0;         // ~22 mm
NG_BOT_H      = 4.0;
NG_TOP_H      = NG_H - NG_BOT_H + WALL;
NG_POUR_D     = 4.0;

// FR-4
NG_FR4_D      = 12.0;
NG_FR4_T      = 1.0;
NG_FR4_Z      = NG_BOT_H - NG_FR4_T;          // = 3.0 mm
NG_FR4_LIP    = 0.2;

// Funnel (scaled)
NG_FUN_TOP_D     = 6.0;
NG_FUN_BOT_D     = 11.0;
NG_FUN_H         = 2.5;
NG_FUN_WALL      = 1.0;

NG_SENSE_TIP_D    = 2.0;
NG_SENSE_PROTRUDE = 0.1;

NG_IMP_RING_Z_FRAC = 0.5;
NG_IMP_RING_W      = 1.0;
NG_IMP_RING_T      = 0.25;

// Cable exit (B-strategy — two opposite round holes)
NG_CABLE_HOLE_D = 1.5;                        // 1 mm cable + 0.5 mm clearance
NG_CABLE_RAD_L  = (NG_MOLD_OD - NG_OD)/2 + 1.0;

// Alignment pins (scaled, 3× — 22 mm OD can't comfortably fit 4)
NG_PIN_D_BASE = 2.0;
NG_PIN_D_TIP  = 1.5;
NG_PIN_H      = 2.0;
NG_HOLE_D     = 1.8;
NG_HOLE_DEPTH = 2.3;
NG_PIN_R      = 3;
NG_PIN_ANGLES = [90, 210, 330];               // avoid cable exits at 0° and 180°

// ═════════════════════════════════════════════════════════════
// HairSite electrode (24 mm + 7 penetration pins)
// Uses EP_ funnel dimensions (same 24 mm body) and EP_ pin params.
// ═════════════════════════════════════════════════════════════
HS_OD         = 24.0;
HS_H          = 12.0;                         // taller to accommodate pins
HS_MOLD_OD    = HS_OD + 2*WALL + 4.0;         // 32 mm
HS_BOT_H      = 6.0;
HS_TOP_H      = HS_H - HS_BOT_H + WALL;
HS_POUR_D     = 6.0;

HS_FR4_D      = EP_FR4_D;
HS_FR4_T      = EP_FR4_T;
HS_FR4_Z      = HS_BOT_H - HS_FR4_T;          // top face flush with top of lower silicone
HS_FR4_LIP    = EP_FR4_LIP;

// Penetration pin array (1 centre + 6 at 60° on 6 mm radius)
HS_PIN_D      = 1.2;                          // penetration pin diameter in mold
HS_PIN_H      = 8.0;                          // post height
HS_PIN_RAD    = 6.0;                          // radius of outer 6 pins
HS_PIN_N      = 7;
HS_PIN_EXCL_R = 0.5;                          // texture exclusion radius around each pin

// ═════════════════════════════════════════════════════════════
// ImpactGuard helmet adapter (unchanged — not part of this redesign)
// ═════════════════════════════════════════════════════════════
IG_OD         = 38.0;
IG_H          = 12.0;
IG_ELEC_D     = 24.5;
IG_ELEC_H     = 8.0;
IG_SNAP_R     = 0.8;
IG_MOUNT_W    = 50.0;
IG_MOUNT_H    = 8.0;

// ═════════════════════════════════════════════════════════════
// Headband mounts (unchanged — not part of this redesign)
// ═════════════════════════════════════════════════════════════
HBA_BAND_W    = 22.0;
HBA_BAND_T    = 2.5;
HBA_ELEC_D    = 24.5;
HBA_ELEC_H    = 6.0;
HBA_CLIP_H    = 12.0;
HBA_CLIP_W    = 30.0;
HBA_SNAP_R    = 0.8;

HBN_BAND_W    = 16.0;
HBN_BAND_T    = 2.0;
HBN_ELEC_D    = 15.5;
HBN_ELEC_H    = 5.0;
HBN_CLIP_H    = 9.0;
HBN_CLIP_W    = 22.0;
HBN_SNAP_R    = 0.6;

// ═════════════════════════════════════════════════════════════
// SHARED MODULES
// ═════════════════════════════════════════════════════════════

// ── Alignment pin / hole primitives (conical for self-release) ──
module alignment_pin_male(d_base, d_tip, h) {
  cylinder(d1 = d_base, d2 = d_tip, h = h, center = false);
}

module alignment_hole(d, depth) {
  cylinder(d = d, h = depth, center = false);
}
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

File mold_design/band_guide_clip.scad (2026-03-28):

// ============================================================
// Headband Guide Clip — Prevents elastic band rolling/twisting
// Print 2 per headband setup. Slides onto the elastic band
// and sits against the head to keep band flat and stable.
// ============================================================

// --- Parametric band dimensions ---
band_width          = 25;        // elastic band width (match adult mount)
band_thickness      = 3;         // elastic band thickness + clearance

// --- Clip body ---
clip_w              = 30;        // total width
clip_h              = 10;        // height (along head surface)
clip_d              = 5;         // depth/thickness of clip

// --- Band slot through clip ---
slot_w              = band_width; // matches band width
slot_h              = band_thickness; // matches band thickness

// --- Smooth edges ---
fillet_r            = 0.3;

$fn                 = 60;

// ============================================================
// Main clip body with band slot
// ============================================================
module band_guide_clip() {
    difference() {
        // Rounded rectangular body
        minkowski() {
            translate([-clip_w/2 + fillet_r, -clip_h/2 + fillet_r, 0])
                cube([clip_w - 2*fillet_r, clip_h - 2*fillet_r,
                      clip_d - fillet_r]);
            sphere(r = fillet_r);
        }

        // Band slot — horizontal through-slot for elastic band
        translate([-slot_w/2, -clip_h/2 - 1, (clip_d - slot_h) / 2])
            cube([slot_w, clip_h + 2, slot_h]);

        // Slight inner curve on skin-facing surface
        // so clip sits flush on rounded head
        translate([0, 0, -80 + fillet_r])
            sphere(r = 80, $fn = 120);
    }
}

band_guide_clip();

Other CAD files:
stl/neoguard_v2_mold_bottom.stl
stl/episcreen_mold_bottom.stl
stl/hairsite_mold_top.stl
stl/neoguard_mold_top.stl
mold_design/episcreen_mold_bottom.scad
mold_design/episcreen_mold_top.scad
mold_design/hairsite_mold_bottom.scad
mold_design/hairsite_mold_top.scad
mold_design/headband_mount_adult.scad
mold_design/headband_mount_neonatal.scad
mold_design/impactguard_cable_clip.scad
mold_design/impactguard_helmet_adapter.scad
mold_design/neoguard_mold_bottom.scad
mold_design/neoguard_mold_top.scad
scad/assembly_cross_section.scad
scad/assembly_exploded.scad
scad/assembly_family.scad
scad/episcreen_mold_bottom.scad
scad/episcreen_mold_top.scad
scad/hairsite_mold_bottom.scad
scad/hairsite_mold_top.scad
scad/headband_mount_adult.scad
scad/headband_mount_neonatal.scad
scad/impactguard_helmet_adapter.scad
scad/neoguard_mold_bottom.scad
scad/neoguard_mold_top.scad
stl/episcreen_mold_top.stl
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

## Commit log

2026-03-28 Add two-part resin 3D-printable mold design for semi-dry EEG electrode
    Parametric OpenSCAD design for silicone casting mold with:
    - Bottom piece: base plate, electrode cavity, FR-4 seat ledge, spiral
    exposure platform, microchannel guide holes, micro-textured surfaces
    - Top piece: reservoir ring protrusion, pour hole, vent holes, cable
    exit channel, reservoir fill port, alignment pins
    - Exported STL files ready for SLA/DLP printing
    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
    [episcreen_mold_bottom.scad, episcreen_mold_cross_section.scad, episcreen_mold_parameters.scad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]
2026-03-28 Add NeoGuard neonatal EEG electrode mold design
    Scaled-down two-part mold optimized for newborn skull:
    - 15mm electrode OD (vs 24mm standard), 7mm height (vs 10mm)
    - 12mm FR-4 seat (vs 19mm), 1.0mm thick (vs 1.6mm)
    - 4 microchannel guides at 90° (vs 3 at 120°) for better coverage
    - Soft gasket rim (0.3mm × 0.5mm) for delicate neonatal skin seal
    - Gentler micro-texture (0.1mm vs 0.15mm depth)
    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
    [neoguard_mold_bottom.scad, neoguard_mold_cross_section.scad, neoguard_mold_parameters.scad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]
2026-03-28 Add ImpactGuard helmet mount adapter and cable routing clip
    Two direct-print functional components for sport/boxing EEG:
    1. Helmet mount adapter (35×35mm curved base plate):
    - 24.5mm electrode seat with 14mm skin-contact through-hole
    - 3 flexible retention clips for snap-fit electrode holding
    - Velcro-compatible bump grid on helmet-facing surface
    - 4 sewing/zip-tie mounting holes at corners
    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
    [impactguard_cable_clip.scad, impactguard_cable_clip.stl, impactguard_helmet_adapter.scad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]
2026-03-28 Add HairSite hair-penetrating pin EEG electrode mold design
    Hair-site variant of EpiScreen with pin array on skin-contact surface:
    - 7 tapered pin wells in hexagonal pattern (1 center + 6 ring at 7mm radius)
    - Pins: 3mm tall, 2mm base tapering to 1.5mm tip with hemispherical dome
    - Capillary web ridges (0.3mm) connecting pin wells for electrolyte wicking
    - Spiral platform flush with pin bases for conductive coating continuity
    - Micro-texture between pins for additional surface grip
    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
    [hairsite_mold_bottom.scad, hairsite_mold_cross_section.scad, hairsite_mold_parameters.scad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]
2026-03-28 Add hairsite bottom mold underside view image
    https://claude.ai/code/session_01SxZYsTGjrnrhSDmZrRwSDf
2026-03-28 Add elastic headband mounting systems for forehead EEG placement
    Two headband mount versions plus band guide clip:
    1. Adult mount (40×30mm, R=85mm curvature):
    - 24.5mm electrode pocket with 18mm skin-contact hole
    - 3 snap-fit retention clips
    - 25mm band threading slots, cable exit groove
    - Pressure distribution ribs to prevent rocking
    2. Neonatal mount (25×20mm, R=55mm curvature):
    - 15.5mm electrode pocket with 10mm skin-contact hole
    - 2 retention clips, ultra-lightweight (1.5mm min wall)
    - 15mm narrow band slots, tape backup tab
    - 0.5mm fillets for neonatal skin safety
    3. Band guide clip (30×10×5mm):
    - Prevents elastic band rolling/twisting on head
    - 25m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
    [band_guide_clip.scad, band_guide_clip.stl, headband_mount_adult.scad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]
2026-03-28 Add EpiScreen electrode mold system: STL files, OpenSCAD sources, and ISEF renders
    - stl/: 9 print-ready STL files generated via trimesh + manifold3d booleans
    episcreen_mold_{bottom,top}.stl — 24 mm standard electrode, 2-part mold
    neoguard_mold_{bottom,top}.stl — 15 mm neonatal electrode, 2-part mold
    hairsite_mold_{bottom,top}.stl — 24 mm + 7 penetrating hair-contact pins
    impactguard_helmet_adapter.stl — snap-fit helmet mount
    headband_mount_{adult,neonatal}.stl — elastic band clips
    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
    [assembly_cross_section.scad, assembly_exploded.scad, assembly_family.scad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]
2026-03-28 Fix: all 9 STLs now watertight (manifold clean pass)
    Three mounting hardware STLs (headband adult/neonatal, helmet adapter)
    had degenerate 2-face ghost shells left by trimesh cone() subtraction.
    Fix in generate_stl.py: after boolean ops, import mesh into manifold3d
    which merges duplicate vertices and closes T-junctions, then export back
    to trimesh. All meshes now pass independent post-load watertight check.
    Full QA: 9/9 STLs watertight + positive volume ✓
    https://claude.ai/code/session_01LzTmkMCMdZzg6YFmStTeGG
    [episcreen_mold_bottom.stl, hairsite_mold_bottom.stl, headband_mount_adult.stl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]
2026-03-30 Add EpiScreen v2 molds: modular pad system + impedance ring
    episcreen_v2_mold_bottom.stl (32×32×6.5 mm, 114k faces, watertight)
    - Retention groove ring at Ø11.5 mm (0.5 mm wide × 0.3 mm deep protrusion)
    → creates annular groove in electrode that accepts pad disc lip
    - Impedance reference ring groove at Ø14.0 mm (0.8 mm wide × 0.5 mm deep)
    → wire ring sits here during casting for impedance sensing
    - Second cable exit slot (2 mm wide) offset from primary, for ring wire
    - Micro-dot texture on cavity floor: hex-packed Ø0.24 mm dots, 0.15 mm deep,
    ~0.5 mm spacing with ±0.1 mm jitter (bio-inspired irregular pattern)
    NOTE: requires SLA ≤0.05 mm layer / ≤0.10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
    [episcreen_v2_mold_top.stl, pad_disc_mold.stl]
2026-03-30 Add EpiScreen v2 mold with 5 design innovations
    Bottom mold (8 changes):
    - Pad retention groove ring (∅11.5mm, 0.5×0.3mm) for press-fit pad disc
    - Fingernail grip flat (1.5mm break at 180°) for pad removal
    - Electrolyte flow port pin (∅1.5×4.5mm) creating reservoir→pad channel
    - Impedance reference ring channel (∅14mm, 0.8×0.5mm) for 26AWG wire embed
    - Wire exit ramp (0.5mm) guiding impedance ring wire to cable notch
    - Second cable exit notch (2.5mm, 1.5mm gap) for impedance ring wire
    - Translucent window bump (0.5mm×25° arc) for electrolyte visibility
    - Bio-mimetic hex dot texture (∅0.25mm, 0.15mm deep, 0.5mm pitch ±jitter)
    Top mold (2 changes):
    - Fill port aligned with fl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
    [episcreen_v2_mold_top.stl]
2026-03-31 Add removable pad disc mold (pad_disc_mold_bottom/top.stl)
    Two-part 18mm mold for casting the user-replaceable EpiScreen pad disc:
    Bottom mold:
    - ∅11.8mm × 2.5mm cavity with 0.3mm convex crown floor
    - Retention lip groove (0.5×0.3mm at 0.5mm from floor) → snap-fit lip on disc
    - Fingernail grip flat (1.5mm, 0°) for easy removal
    - ∅1.5mm centre through-pin → electrolyte flow hole
    - 3× radial channels (0.3×0.2mm, 120°) → capillary electrolyte distribution
    - Hex dot texture (∅0.25mm, 0.15mm, 0.5mm pitch) on skin-contact surface
    - 2× ∅1.5mm alignment pin holes
    Top mold (lid):
    - ∅8mm × 0.3mm contact pad bump → raised contact pad on disc
    - Annular absorbent ring protrusi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
    [pad_disc_mold_top.stl]
2026-03-31 Add NeoGuard v2 molds with scaled 5-mod update + neonatal pad disc
    NeoGuard v2 bottom mold (∅22mm × 5.5mm):
    - Pad retention groove ∅7.5mm, 0.4×0.25mm + 1.2mm fingernail grip
    - Flow port pin ∅1.2mm × 4.0mm (centred, aligned with top fill port)
    - Impedance ring channel ∅9.0mm, 0.6×0.4mm + wire exit ramp
    - Second cable exit notch 2.0mm (1.2mm wall from primary 2.5mm notch)
    - Translucent window bump 4mm arc (30.9°), 0.5mm thick at reservoir height
    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
    [neoguard_pad_disc_mold_top.stl, neoguard_v2_mold_bottom.stl, neoguard_v2_mold_top.stl]
2026-04-01 Add EEG signal quality classifier with synthetic data pipeline
    Complete pipeline: synthetic EEG generation (256 Hz, 30 min with
    eye blinks, muscle, electrode pop, 50 Hz noise, head movement
    artifacts), bandpass/notch filtering, 2s windowed feature extraction
    (time/frequency/nonlinear), model training (RF/SVM/GBT with CV),
    visualization (5 figures), and real-time prediction function.
    https://claude.ai/code/session_01Qux3SQrmeF3inXD8ajv4Xf
    [features.csv]
2026-04-01 Add epilepsy detection transfer learning pipeline
    Build complete pipeline to evaluate whether a seizure detection model
    trained on clinical CHB-MIT-like EEG data can transfer to a low-cost
    single-channel FP1 semi-dry electrode. Includes synthetic data generation
    (5 patients with seizure events), 13-feature extraction, Random Forest
    and MLP classifiers with leave-one-patient-out CV, transfer evaluation
    with domain shift analysis, and 6 publication-quality visualizations.
    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
2026-04-01 Add amplitude-integrated EEG (aEEG) module for neonatal seizure monitoring
    Signal processing pipeline: bandpass filter (2-15 Hz, 4th-order Butterworth),
    rectification, Hilbert envelope detection, 1 Hz downsampling, and semi-log
    trend display. Rule-based classification (CNV/DNV/BS/LV/FT) using upper/lower
    margin percentiles in 60-second windows. Seizure detection via bandwidth
    narrowing and rapid lower-margin rise criteria.
    Includes synthetic 4-hour neonatal EEG generator with normal, discontinuous,
    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
    [classification_log.csv]
2026-04-18 Redesign EEG electrode molds around funnel-integrated geometry
    Apply the PDF spec to all three variants (EpiScreen / NeoGuard /
    HairSite), replacing the reservoir-ring + spiral-platform design with
    a funnel that doubles as electrolyte reservoir and hosts the impedance
    ring on its inner wall.
    Key changes:
    - CLEARANCE 0.3 -> 0.5 and DRAFT 2 -> 4 for Ecoflex 00-50
    - Cable exits are now fully enclosed through-tunnels in bottom mold
    only; cable_exit_top() removed. EpiScreen/HairSite use C-strategy
    (two channels + 2 mm divider); NeoGuard uses B-strategy (two
    opposite 1.5 mm round holes)
    - Funnel void + sensing tip (0.1 mm protrude) + generous impedance
    ring recess on inner funnel wall (>=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
    [episcreen_mold_bottom.scad, episcreen_mold_cross_section.scad, episcreen_mold_parameters.scad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]
2026-04-18 Update print statement from 'Hello' to 'Goodbye'
